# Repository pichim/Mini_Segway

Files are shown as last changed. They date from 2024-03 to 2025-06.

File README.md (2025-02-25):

# MiniSegway

The Segway is a robot that has the ability to balance itself using two motors and an IMU sensor. It is controlled with a radio transmitter in two modes, a car where it moves on the ground maintaining three points of support but also as a segway, that is, balancing on two wheels. 

<p align="center">
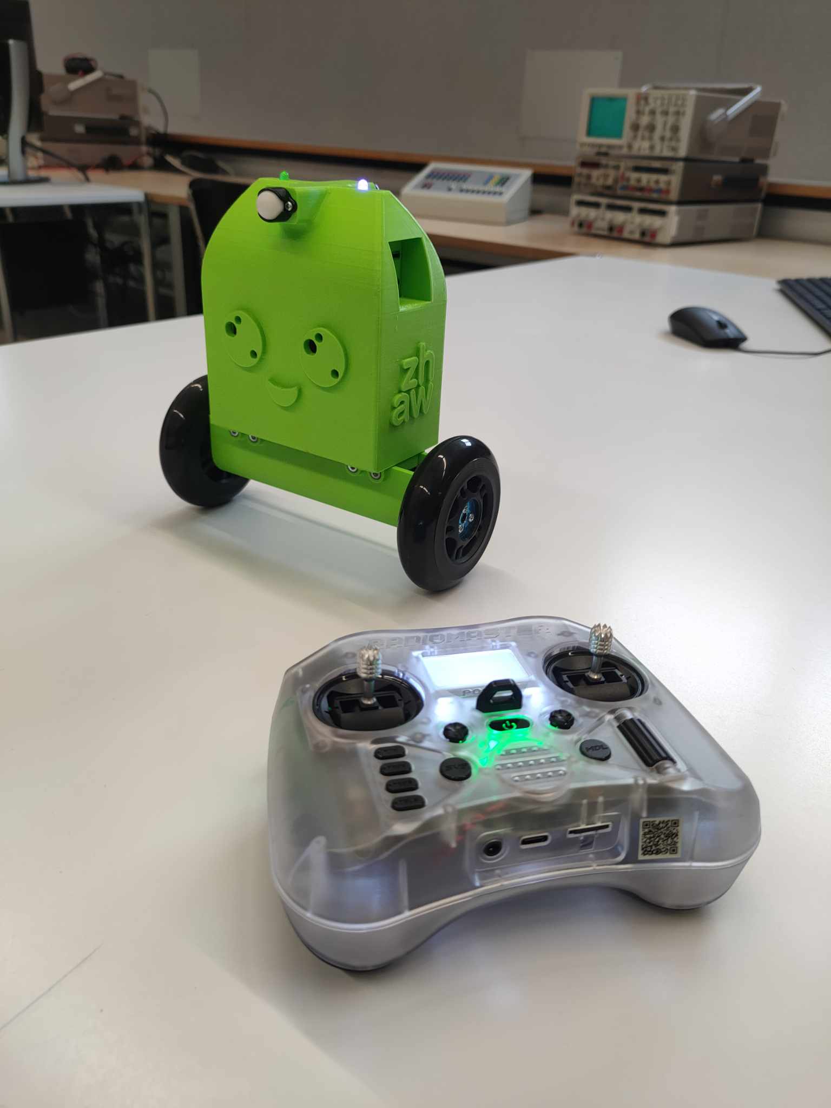
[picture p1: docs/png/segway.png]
Segway
     </br>
    <i>Segway with radio</i>
</p>

## Table of Contents

1. [Repository structure](#repository-structure)
2. [Hardware](#hardware)
3. [Prerequisites](#prerequisites)
4. [User manual](#user-manual)
5. [Software](#software)
6. [Notes](#notes)

## Repository structure

- ``/docs/cad`` - cad files with division into different extensions, including print-ready STL files and STEP files. <br>
- ``/docs/hardware`` - folder contains all hardware's datasheets and list <br>
- ``/docs/matlab`` - folder contains all development files in matlab <br>
- ``/docs/papers`` - folder contains all scientific papers regarding segway development 

## Hardware

Mechanical components (ordered) employed in design: 

- [Scooter/Skate Wheel 84×24mm][12] <br>
- [Pololu Aluminum Scooter Wheel Adapter for 4mm Shaft][13] <br>
- 2 x [Pololu Ball Caster with 1/2″ Plastic Ball][17] 

All frame parts 3D models are localized in ``docs/cad/`` folder

The list of eletric components varies from version to version, as a special PCB has been designed to eliminate some of the components and allow the battery to be charged directly on the robot. In the absence of a PCB, a list of stock components is provided.

**VERSION WITHOUT PCB**

Electrical components and sensors:

- [Nucleo-F446RE][1] <br> 
- [Pololu Dual MC33926 Motor Driver Shield for Arduino][2] <br>
- 2 x [47:1 Metal Gearmotor 25Dx67L mm MP 12V with 48 CPR Encoder][3] <br>
- [MPU6500 - 6DOF IMU][4] <br>
- [OpenLager Blackbox][5] <br>
- [RadioMaster RP2 ELRS 2.4GHz Nano Receiver][6] <br>
- [0,28" Mini Digital-Voltmeter mit LED Anzeige, 3,2-30V, 2-Wire, red][7] <br>
- [Pololu mini push-button switch][8] <br>
- 3 x [Mini Pushbutton Switch: PCB-Mount][9] <br>
- 2 x [Conrad energy NiMH battery packs 6V, 2300mAh][10] <br>
- [RadioMaster Pocket Radio Controller (ELRS)][11]<br>
- [Micro BEC 7-21V to 5V/12V-ADJ][15] <br>
- [Charger model 220v 0.5a 1a volcraft mw6168v][16] <br>
- 2 x LED diode <br>
- Jumper wires

The electronics connection is included in the file, which can be found [HERE](/docs/hardware/Segway_connection_diagram_F446RE.pdf)

**VERSION WITH PCB**

- [Nucleo-F446RE][1] <br> 
- [Pololu Dual MC33926 Motor Driver Shield for Arduino][2] <br>
- 2 x [47:1 Metal Gearmotor 25Dx67L mm MP 12V with 48 CPR Encoder][3] <br>
- [MPU6500 - 6DOF IMU][4] <br>
- [OpenLager Blackbox][5] <br>
- [RadioMaster RP2 ELRS 2.4GHz Nano Receiver][6] <br>
- [0,28" Mini Digital-Voltmeter mit LED Anzeige, 3,2-30V, 2-Wire, red][7] <br>
- [Mini Slide Switch: 3-Pin, SPDT, 0.3A][14] <br>
- 2 x [Mini Pushbutton Switch: PCB-Mount][9] <br>
- 2 x [Conrad energy NiMH battery packs 6V, 2300mAh][10] <br>
- [RadioMaster Pocket Radio Controller (ELRS)][11]<br>
- [Charger model 220v 0.5a 1a volcraft mw6168v][16] <br>
- Custom PCB
- 2 x LED diode <br>
- Jumper wires

The electronics connection is included in the file, which can be found [HERE](/docs/hardware/Segway_connection_diagram_F446RE_with_PCB.pdf) <br>
All the files related to PCB can be found in ``docs/segway_charging_board/``

Below there is components placement shown:

<p align="center">
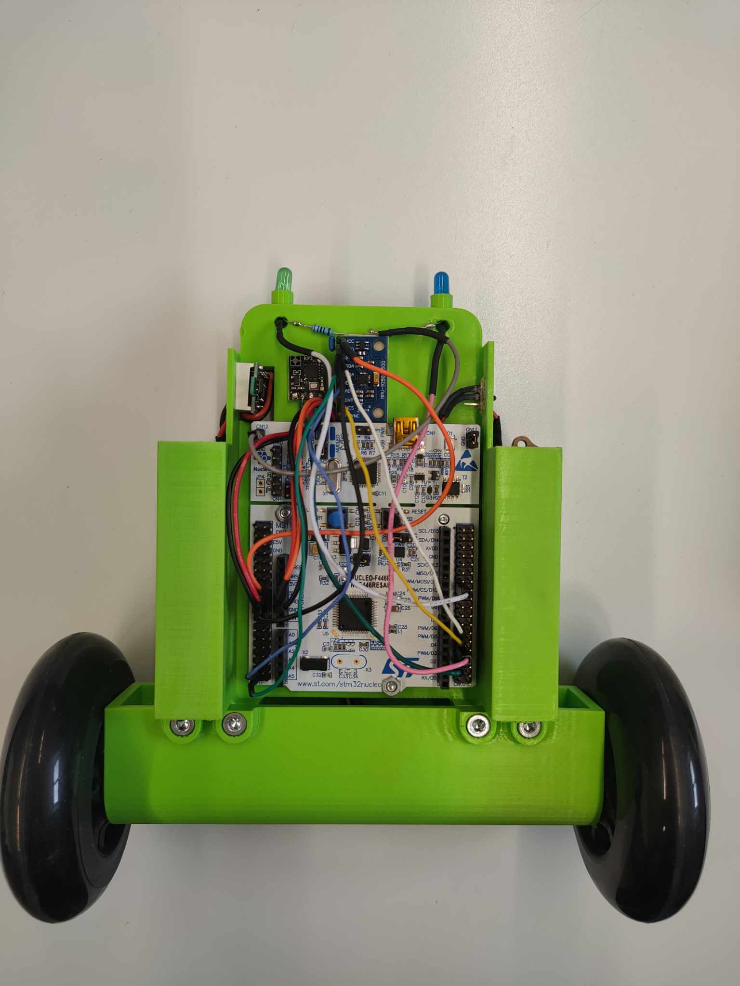
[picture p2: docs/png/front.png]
Front
     </br>
    <i>Front</i>
</p>

<p align="center">
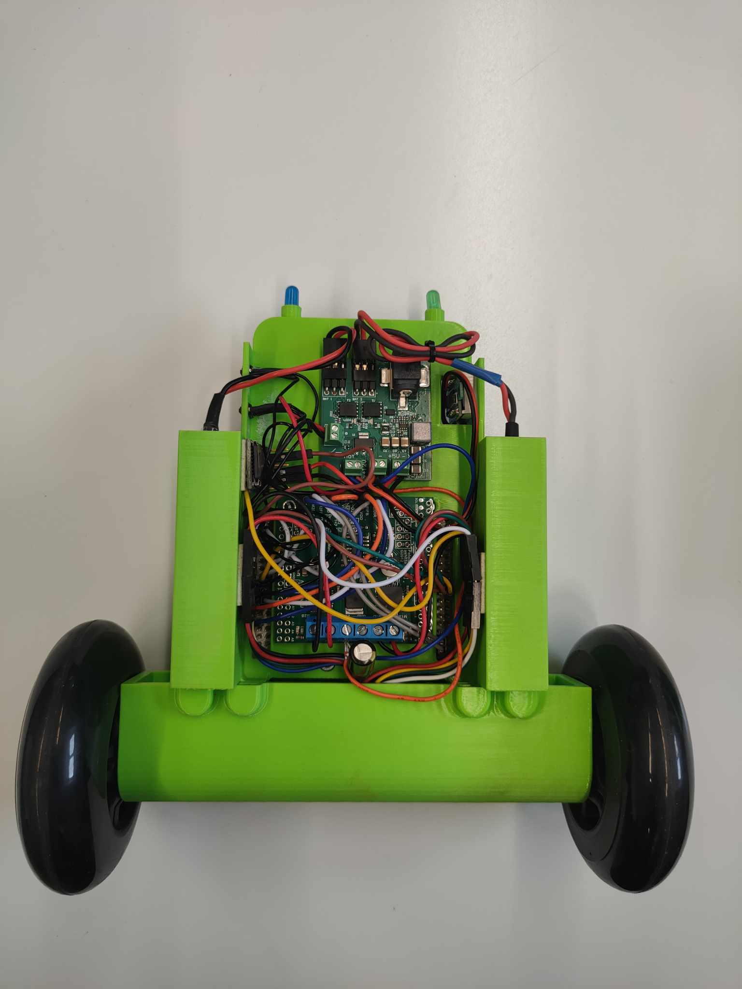
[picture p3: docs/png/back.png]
Back
     </br>
    <i>Back</i>
</p>

## Prerequisites

- Mbed Studio
- Libraries:
    - mbed-os 6.17.0
    - eigen

All the libraries you need are included in the repository. Software is mostly based on files located in /src folder and main logic is included in MiniSegway class that is running in own thread.

## User manual

### Running the project for the first time

In order to run the project you need to import program to Mbed Studio and follow next steps:
- as the board is using external power source, board has jumper JP5 switched to E5V postion which requires to first supply board with external power and then plug it in to the computer
- now program can be compiled and flashed to the board

### Using robot

In order to use the robot you must follow the steps below:
- Start the radio controller that is paired with the receiver on the robot
- Turn on the power supply on the robot (in this situation both LED, green and blue will start blinking)
- Arm the radio controler (SD button) (in such case the green LED will start to shine continuously)
- Then the USER button on the robot can be pressed, which will lead the robot to CAR mode (blue LED will start to shine continuously) [picture below]
- To use the robot as segway, raise it to a standing position and wait until the robot visibly starts to balance.
- By default, the robot is in normal mode, however, when you press the button on the radio transmitter (SA button), the robot will go into fast mode, and its speed will be increased (**NOTES: In normal mode, the robot is practically unturnable when controlling the radio transmitter (as long as there is no collision, of course), however, in fast mode there is the possibility of such control, which will lead to loss of balance.**)

<p align="center">
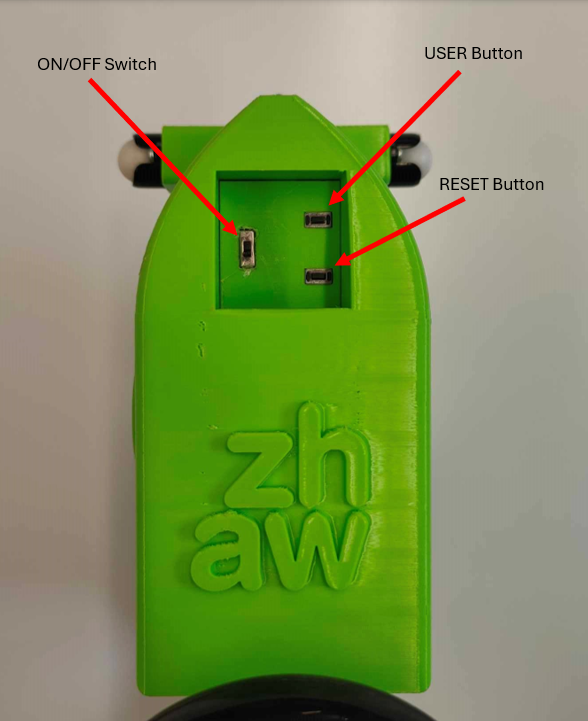
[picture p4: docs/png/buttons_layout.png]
Buttons layout
     </br>
    <i>Button layout</i>
</p>

## Software

### main.cpp

The *main.cpp* file contains only the declaration of the rc class, which handles communication with the radio transmitter, and the minisegway, which contains all the program logic. Inside the file you can also find the declaration of an additional button that serves as the RESET of the system.

### config.h

The *config.h* file is very important due to the fact that it contains all the declarations of the robot's parameters and the names of the pins used to connect the hardware. Importantly, it also contains options for changing the robot's configuration, i.e. enabling or disabling certain options such as data transfer (over the link or to an SD card), measurements with additional current sensors, or a function for testing the frequency response with a chirp signal. 
This file should be used for all configurations related to changing the parameters of the robot, changing the parameters of the filters and any changes to the pin maps.

### minisegway.cpp

Minisegway is a class that operates in its own thread with a frequency of 1kHz. In it there are declarations of all objects communicating with the hardware that is mounted on the robot. Inside the class you can find the state machine, because as mentioned the robot moves in two modes, as a car or as a segway. The file also includes additional functions, used during debugging and testing of the hardware operation.

#### IMU

The IMU class is initialized when the MiniSegway class is initialized, the first step that is performed inside the IMU is to configure and check the connection which is signaled by returning the device ID to the output window.The device is then calibrated, with the first thousand measurement points omitted due to the fact that they deviate significantly from the norm and there are fluctuations associated with the initialization process.

In addition, position mapping is performed due to the target position of the robot and the positioning of the IMU on the robot:

1. **Roll Control Advantage**: The alignment allows the use of roll for controlling the Segway. Roll control is preferred because yaw control can encounter singularities (undefined or unstable behavior) at angles of ±90 degrees when the Segway is upright.

2. **IMU Orientation**:
   - **X-Axis**: The IMU's x-axis is oriented to point to the left side of the Segway.
   - **Y-Axis**: The IMU's y-axis is oriented to point towards the back of the Segway.
   - **Z-Axis**: The IMU's z-axis is oriented to point upwards.

In case of completion of the calibration process, a flag is sent confirming the completion of the process so that further execution of the program in the minisegway class can be executed.

#### State space controller

This state-space controller is designed to keep a Segway in a vertical position by controlling the robot's velocity input based on various sensor readings and setpoints. The control strategy involves multiple proportional (P) and derivative (D) components applied to different states of the system:

1. **Position Control ( u_p_{pos} )**:
   - **Proportional Control on Position**: 
     - `robotVelSetpointIntegrator.apply(robot_vel_setpoint(0))` is the integrated velocity setpoint, which essentially gives the desired position setpoint.
     - `robot_pos(0)` is the current position of the Segway.
     - `MINI_SEGWAY_CP_POS_KP` is the proportional gain for position control.
     - The difference between the desired position setpoint and the current position is multiplied by the proportional gain to produce the position control effort `u_p_pos`.

2. **Velocity Control (u_p_{vel}  and u_d_{vel})**:
   - **Proportional Control on Velocity**:
     - `robot_vel(0)` is the current velocity of the Segway.
     - `MINI_SEGWAY_CPD_VEL_KP` is the proportional gain for velocity control.
     - The current velocity is multiplied by the proportional gain to produce the velocity control effort `u_p_vel`.
   - **Derivative Control on Velocity**:
     - `acc_x_filtered` is the filtered acceleration along the x-axis.
     - `MINI_SEGWAY_CPD_VEL_KD` is the derivative gain for velocity control.
     - The filtered acceleration is multiplied by the derivative gain to produce the velocity derivative control effort `u_d_vel`.

3. **Angle Control (u_p_{ang} and u_d_{ang})**:
   - **Proportional Control on Angle**:
     - `imu_data.rpy(0)` is the roll (angle) of the Segway as measured by the IMU (Inertial Measurement Unit).
     - `MINI_SEGWAY_CPD_ANG_KP` is the proportional gain for angle control.
     - The roll angle is multiplied by the proportional gain to produce the angle control effort `u_p_ang`.
   - **Derivative Control on Angle**:
     - `gyro_theta_filtered` is the filtered angular velocity (rate of change of angle).
     - `MINI_SEGWAY_CPD_ANG_KD` is the derivative gain for angle control.
     - The filtered angular velocity is multiplied by the derivative gain to produce the angle derivative control effort `u_d_ang`.

4. **Combining Control Efforts**:
   - The control efforts from the position, velocity, and angle controllers are combined to produce the total control input.
   - The equation `robot_vel_input(0) = -1.0f * (u_p_pos - (u_p_vel + u_d_vel + u_p_ang + u_d_ang))` combines these efforts. The negative sign indicates that the control input is used to counteract deviations from the desired state, aiming to keep the Segway upright.

## Notes:

In the event that a version of Segway will be assembled that does not have a custom PCB, the arrangement of additional hardware will cause the IMU to be on the other side of the robot. In this case, changes must be made to the software in order for the robot to function properly. In the 45th line of **IMU.cpp** file located in ``src`` folder, is following code, that is working only with the version with custom PCB:

```
    // segway imu alignment:
    // the alignment was chosen so that roll can be used for controlling
    // the segway since yaw has a singularity at +/-90 deg
    //   when standing upright, the IMU is mounted on the robot with:
    //   - the x-axis pointing to the right
    //   - the y-axis pointing forwards
    //   - the z-axis pointing upwards
    Eigen::Vector3f gyro(m_ImuMPU6500.gyroX, -m_ImuMPU6500.gyroZ, m_ImuMPU6500.gyroY);
    Eigen::Vector3f acc(m_ImuMPU6500.accX, -m_ImuMPU6500.accZ, m_ImuMPU6500.accY);
```

To match the code to a different orientation of the IMU, i.e., located on the other side of the robot, you need to change the characters of the data coming from each axis as shown in the illustration below.

```
    // segway imu alignment:
    // the alignment was chosen so that roll can be used for controlling
    // the segway since yaw has a singularity at +/-90 deg
    //   when standing upright, the IMU is mounted on the robot with:
    //   - the x-axis pointing to the left
    //   - the y-axis pointing backwards
    //   - the z-axis pointing upwards
    Eigen::Vector3f gyro(-m_ImuMPU6500.gyroX, m_ImuMPU6500.gyroZ, m_ImuMPU6500.gyroY);
    Eigen::Vector3f acc(-m_ImuMPU6500.accX, m_ImuMPU6500.accZ, m_ImuMPU6500.accY);
```

[1]: https://os.mbed.com/platforms/ST-Nucleo-F446RE/
[2]: https://www.play-zone.ch/en/pololu-dual-mc33926-motor-driver-shield-for-arduino.html
[3]: https://www.pololu.com/product/4865
[4]: https://www.smart-prototyping.com/MPU6500-6DOF-Sensor-Breakout-Board
[5]: https://www.racedayquads.com/products/airbot-openlager-blackbox
[6]: https://fpvracing.ch/de/funksystem/3575-radiomaster-rp2-elrs-24ghz-nano-receiver.html?
[7]: https://www.berrybase.ch/0-28-mini-digital-voltmeter-mit-led-anzeige-3-2-30v-2-wire-rot
[8]: https://www.pololu.com/product/2808
[9]: https://www.pololu.com/product/1400
[10]: https://www.conrad.ch/de/p/reely-modellbau-akkupack-nimh-6-v-2300-mah-zellen-zahl-5-mignon-aa-side-by-side-jr-buchse-2613252.html
[11]: https://fpvracing.ch/de/funksystem/3785-radiomaster-pocket-radio-controller-elrs.html?
[12]: https://www.pololu.com/product/3275
[14]: https://www.pololu.com/product/1408
[13]: https://www.pololu.com/product/2672
[15]: https://www.mateksys.com/?portfolio=mbec2a#tab-id-2
[16]: https://eclats-antivols.fr/en/ean/24811-chargeur-de-modelisme-220-v-1-a-voltcraft-mw6168v-nicd-nimh-4016138642414.html
[17]: https://www.pololu.com/product/952

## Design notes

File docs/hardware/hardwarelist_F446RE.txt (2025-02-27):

Nucleo-F446RE
- https://os.mbed.com/platforms/ST-Nucleo-F446RE/

Pololu Dual MC33926 Motor Driver Shield for Arduino
- https://www.play-zone.ch/en/pololu-dual-mc33926-motor-driver-shield-for-arduino.html

2 x 47:1 Metal Gearmotor 25Dx67L mm MP 12V with 48 CPR Encoder
- https://www.pololu.com/product/4865

MPU6500 - 6DOF IMU
- https://invensense.tdk.com/products/motion-tracking/6-axis/mpu-6500/
- https://www.smart-prototyping.com/MPU6500-6DOF-Sensor-Breakout-Board
- MPU-6500-Register-Map2.pdf
- PS-MPU-6500A-01-v1.3.pdf
- 1.71-3.45V

OpenLager Blackbox
- https://www.racedayquads.com/products/airbot-openlager-blackbox
- 3.3-5.5V

RP1 V2 ExpressLRS 2.4ghz Nano Receiver
- https://www.radiomasterrc.com/products/rp1-expresslrs-2-4ghz-nano-receiver
- 5V

0,28" Mini Digital-Voltmeter mit LED Anzeige, 3,2-30V, 2-Wire, red
- https://www.berrybase.ch/0-28-mini-digital-voltmeter-mit-led-anzeige-3-2-30v-2-wire-rot

Pololu mini push-button switch with reverse polarity protection
- https://www.pololu.com/product/2808

3 x Mini Pushbutton Switch: PCB-Mount, 2-Pin, SPST, 50mA (5-Pack)
- https://www.pololu.com/product/1400

2 x LED diode

2 x Conrad energy NiMH battery packs 6V, 2300mAh
- https://www.conrad.ch/de/p/reely-modellbau-akkupack-nimh-6-v-2300-mah-zellen-zahl-5-mignon-aa-side-by-side-jr-buchse-2613252.html

Jumper wires	

GS-9018 Servo
- http://www.goteckrc.com/ProductShow.asp?ID=10

Micro BEC 6-30V to 5V/9V-ADJ
- https://www.mateksys.com/?portfolio=mbec6s

CADDXFPV Nebula Pro Vista Kit
- https://caddxfpv.com/products/nebula-pro-vista-kit-720p-120fps-low-latency-hd-digital-fpv-system

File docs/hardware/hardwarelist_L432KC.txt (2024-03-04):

NUCLEO-L432KC
- https://os.mbed.com/platforms/ST-Nucleo-L432KC/
- https://community.st.com/t5/stm32-mcus-boards-and-hardware/how-to-power-nucleo-f303k8-or-nucleo-l432kc-with-an-external/td-p/111820

MATEKSYS Micro BEC 6-30V to 5V/9V-ADJ
- https://www.mateksys.com/?portfolio=mbec6s
- Input 6-30V
- Output 5V, 1.5A cont., 2.5A max

2x SparkFun 9DoF Sensor Stick
- https://www.sparkfun.com/products/retired/13944
- lsm9ds1.pdf
- 1.9-3.6V

OpenLager
- https://www.racedayquads.com/products/airbot-openlager-blackbox
- 3.3-5.5V

TBS CROSSFIRE Nano RX
- https://www.team-blacksheep.com/products/prod:crossfire_nano_rx
- tbs-crossfire-nano-quickstart.pdf
- 5V

Pololu A4990 Dual Motor Driver Carrier
- https://www.pololu.com/product/2137
- A4990-Datasheet.pdf
- a4990-dual-motor-driver-carrier-schematic-diagram.pdf
- https://www.pololu.com/product/2512
- https://github.com/pololu/a4990-motor-shield
- Enable 2.0-5.0V
- Motor power 6-32V

2x Pololu 298:1 Micro Metal Gearmotor HPCB 12V with Extended Motor Shaft
- https://www.pololu.com/product/3056

2x Pololu 150:1 Micro Metal Gearmotor HPCB 12V with Extended Motor Shaft
- https://www.pololu.com/product/3053

Pololu Magnetic Encoder Pair Kit for Micro Metal Gearmotors, 12 CPR, 2.7-18V
- https://www.pololu.com/product/3081
- 2.7-18.0V

Optical Encoder Pair Kit for Micro Metal Gearmotors, 5V
- https://www.pololu.com/product/2590

Pale Blue PB-9V
- https://www.digitec.ch/en/s1/product/pale-blue-pb-9v-2-pcs-9v-500-mah-batteries-17438462
- https://paleblueearth.com/products/pale-blue-lithium-ion-rechargeable-9v-batteries

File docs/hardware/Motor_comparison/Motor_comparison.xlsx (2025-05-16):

Motor
Brand, series | Pololu 47:1 Metal Gearmotor 25Dx67L mm MP 12V with 48 CPR Encoder |  | A-max 22 Ø22 mm, Graphite Brushes, 6 Watt, with terminals Part number 110161 / 353025 | A-max 22 Ø22 mm, Graphite Brushes, 6 Watt, with terminals Part number 110160 / 231171 | DC-max 22 S Ø22 mm, graphite brushes, ball bearings
Comparing position
Nominal voltage (V) | 12 |  | 12 | 12 | 12
No load speed (RPM) | 7964.5 |  | 9170 | 10200 | 7140 | 1.280683031
Nominal speed (RPM) | - |  | 6000 | 7060 | 5260
No load current (mA) | - |  | 40.5 | 45.8 | 28.3
Nominal current (A) | - |  | 0.613 | 0.681 | 0.819
Stall current (A) | - |  | 1.72 | 2.17 | 3.14
Nominal torque (mNm) | 6.59 |  | 6.95 | 6.96 | 12.5
Stall torque (mNm) | 22.34 |  | 20.9 | 23.7 | 49.4
Shaft diameter (mm) | - |  | 2 | 2 | 2
Shaft length (mm) | - |  | 6.5 | 6.5 | 10
Torque constant (mNm/A) | 10.72 |  | 12.1 | 10.9 | 15.8 | 1.318350179
Speed constant (RPM/V) | 663.71 |  | 790 | 875 | 606
Weight (g) | - |  | 54 | 54 | 54
Size (mm) | 25D x 30.8L |  | 22D x 31.9L | 22D x 31.9L | 22D x 32L
Max power (W) (mechanical) | - |  | 6 | 6 | 8
Price (for 10 units) | - |  | 68.52 | 59.79 | 72.84
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

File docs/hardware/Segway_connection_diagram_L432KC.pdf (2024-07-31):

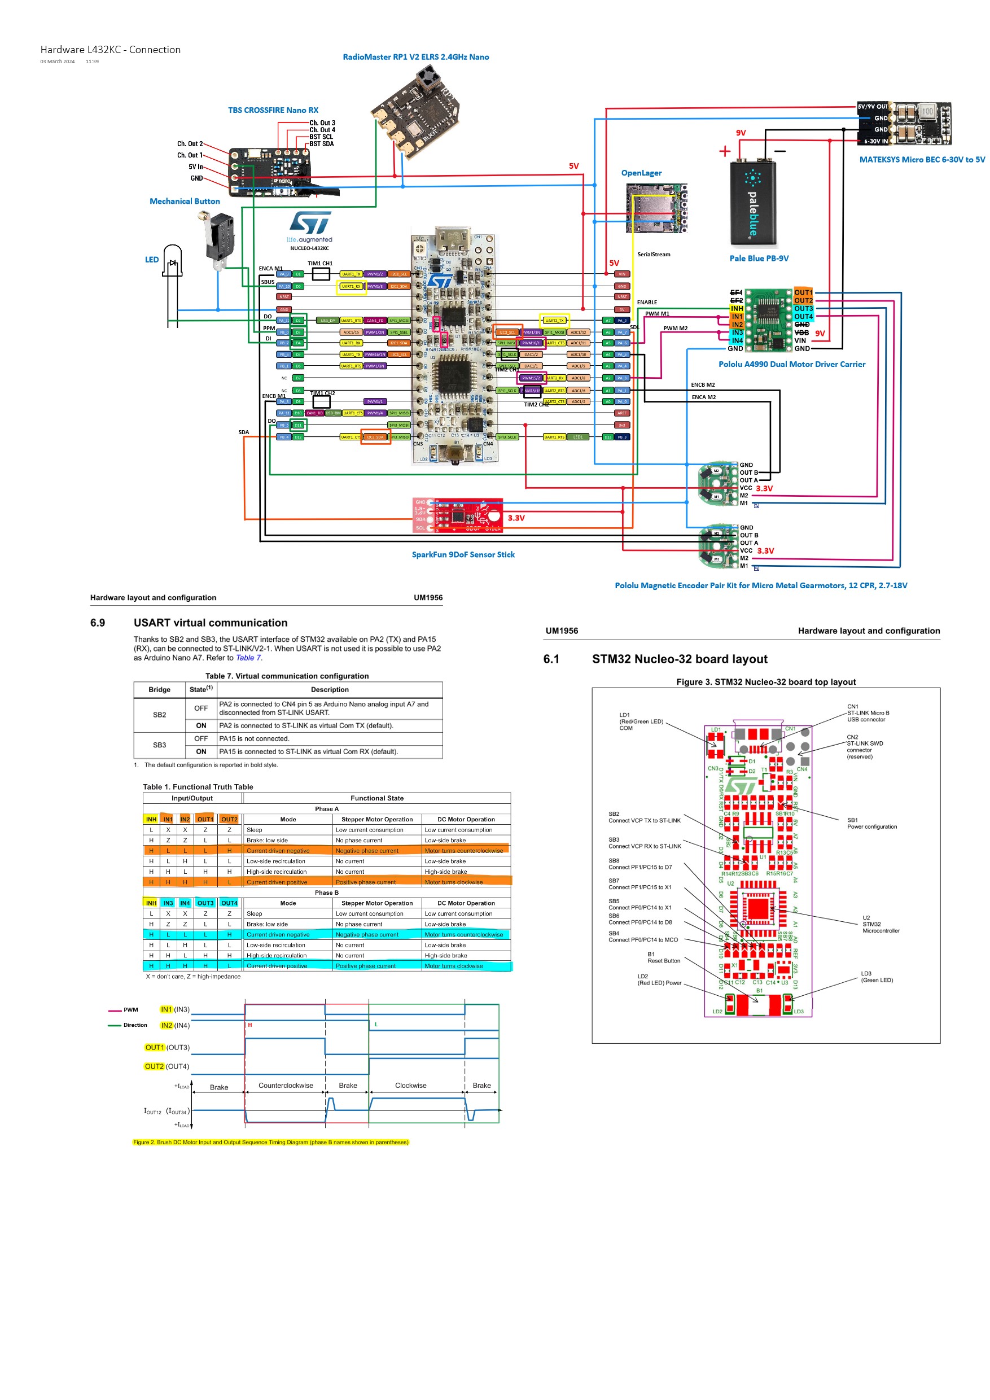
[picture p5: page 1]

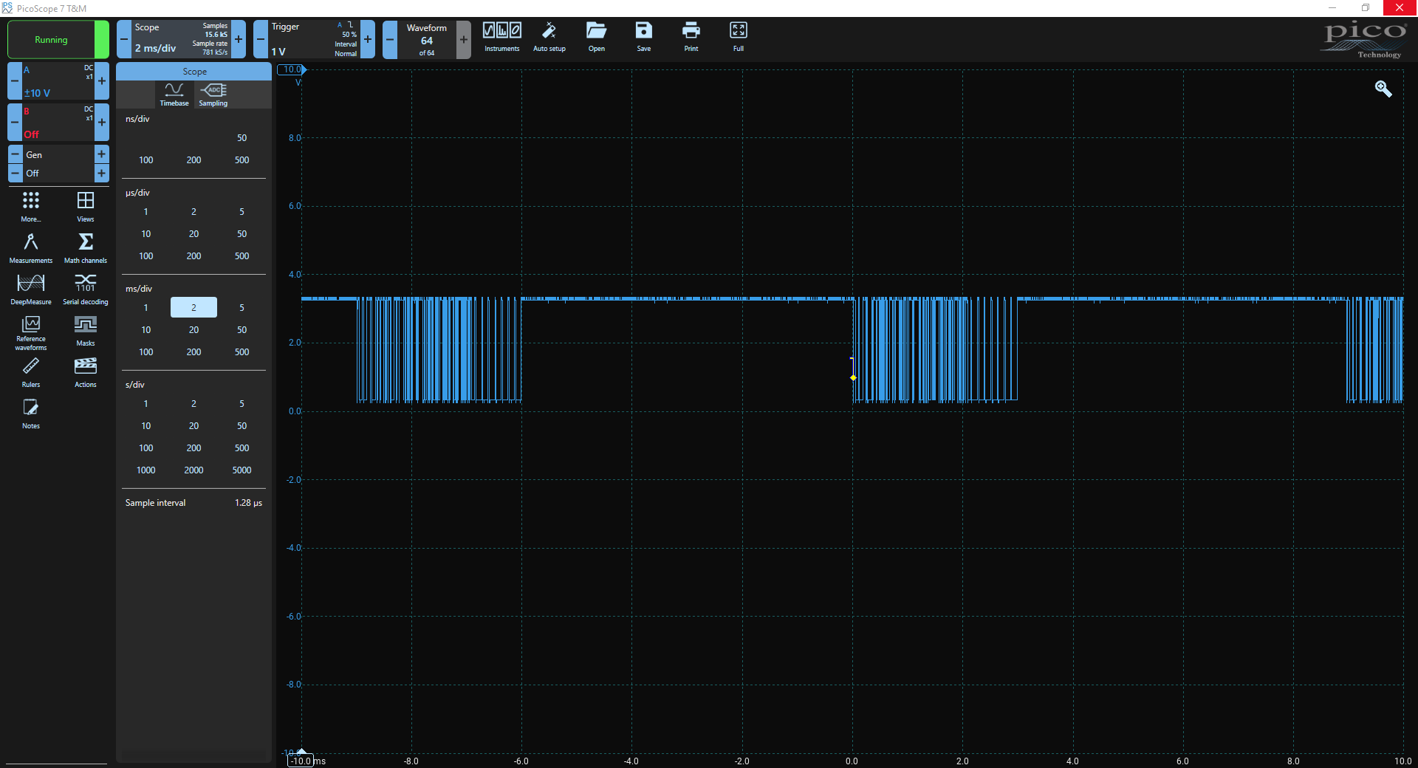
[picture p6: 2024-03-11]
docs/hardware/elrs_sbus/20240229_picoscope_snapshot.PNG

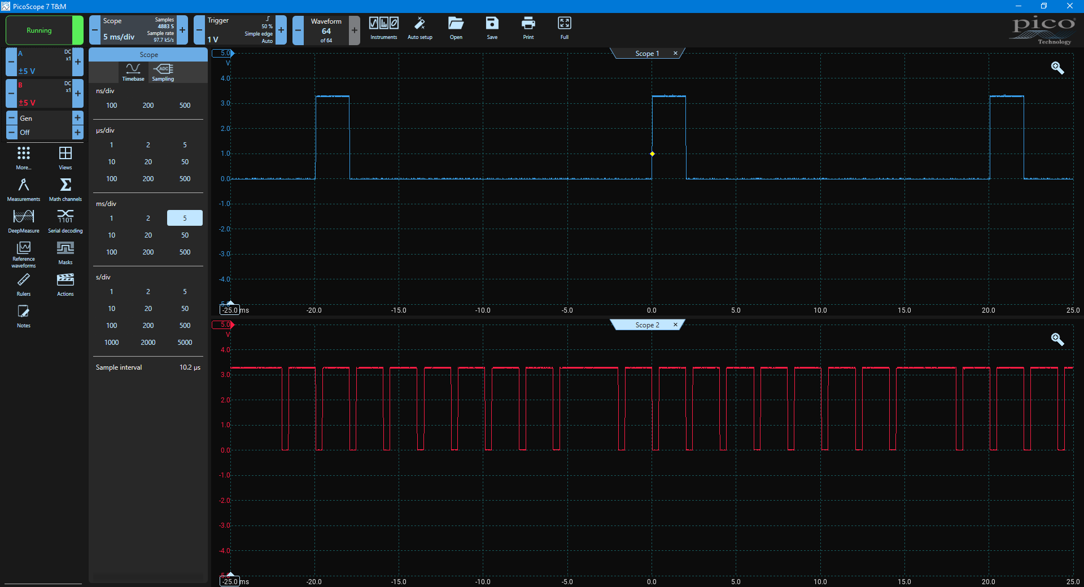
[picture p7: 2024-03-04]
docs/hardware/elrs_sbus/20240229_picoscope_snapshot_8_channels_all_max.PNG

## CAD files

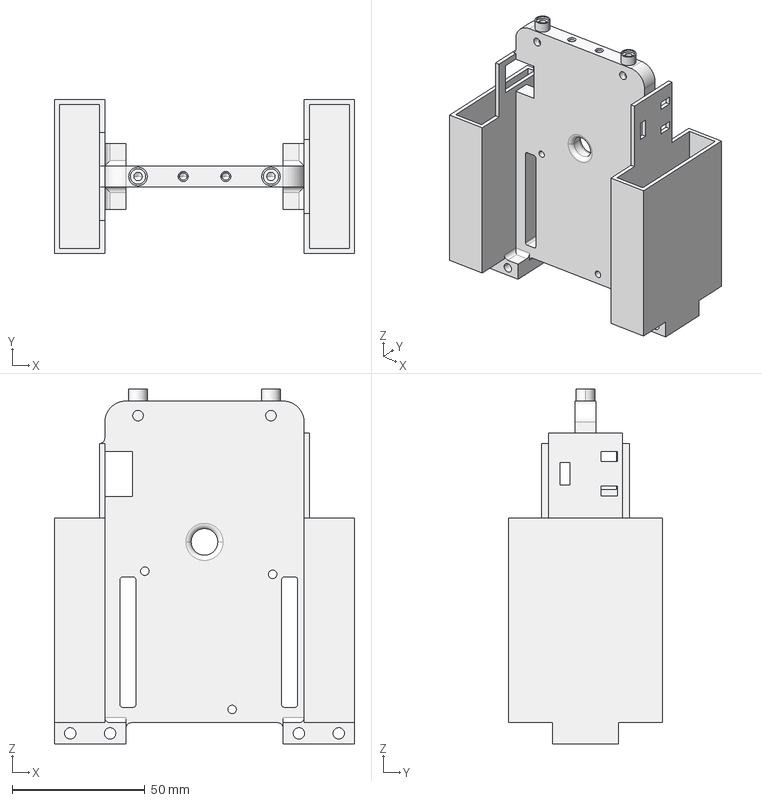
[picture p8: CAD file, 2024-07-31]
docs/cad/NDT_FRAME_MAIN_V1.stp
113.0 x 58.0 x 133.5 mm

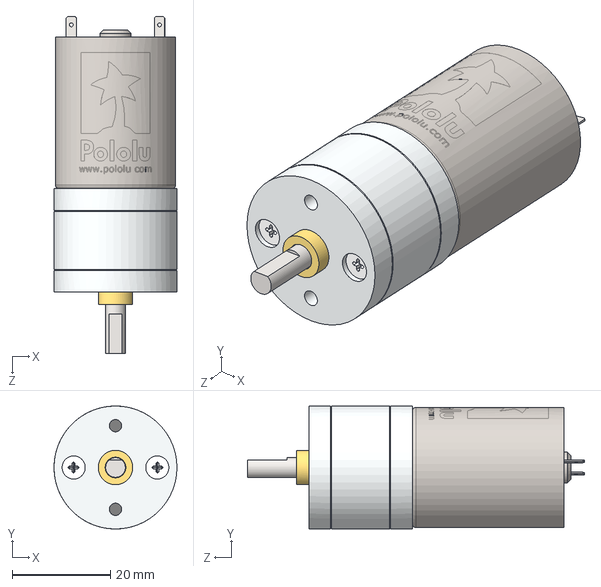
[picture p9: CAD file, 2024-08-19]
docs/cad/25d-metal-gearmotor-34-47.step
25.0 x 25.0 x 68.5 mm

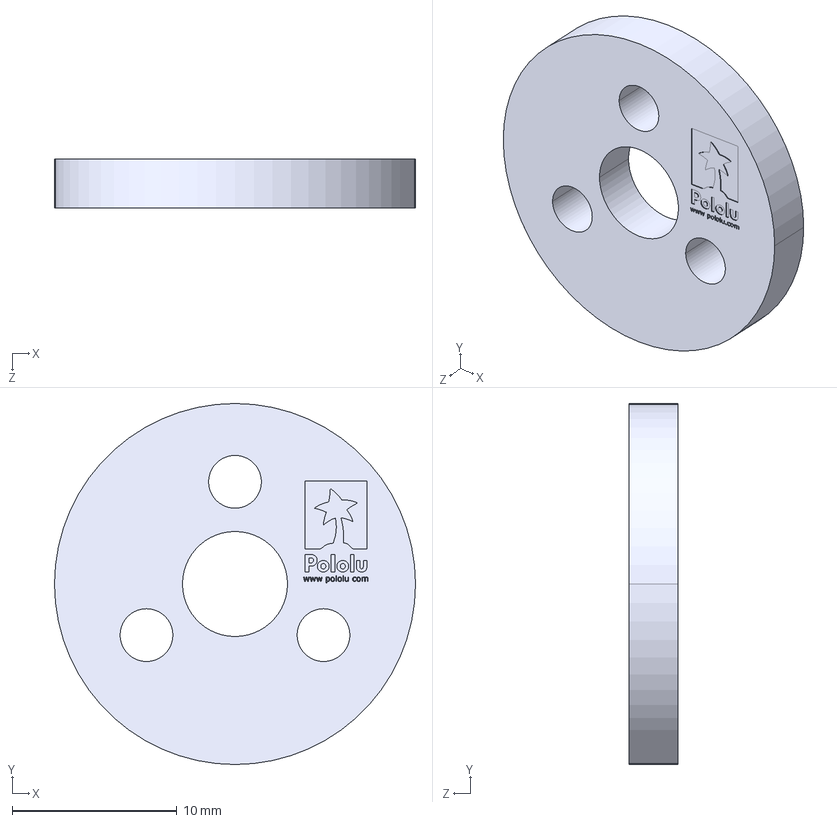
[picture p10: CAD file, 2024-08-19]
docs/cad/pololu-aluminum-scooter-wheel-adapter-dwa01b.step
21.9 x 21.9 x 3.00 mm

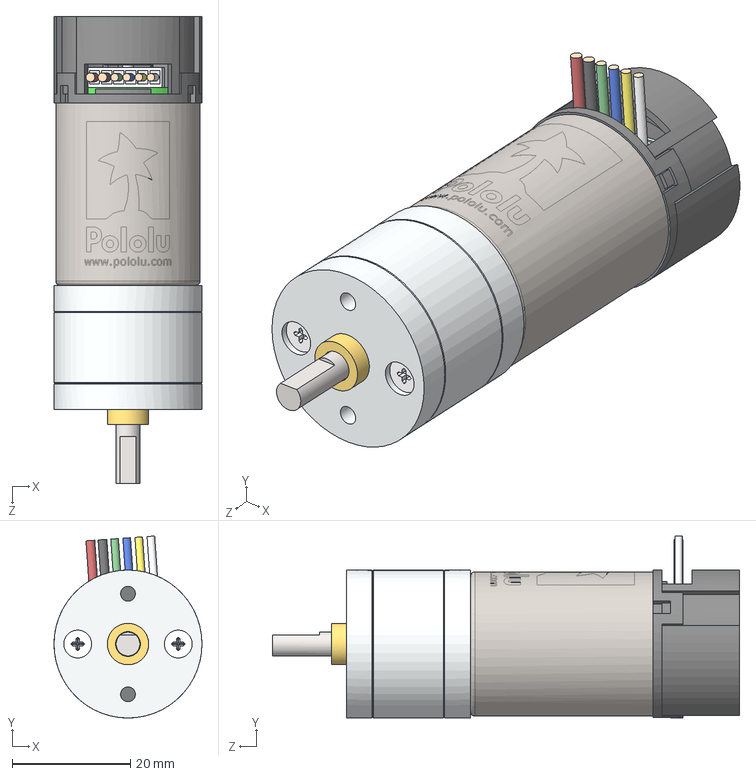
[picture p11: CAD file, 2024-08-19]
docs/cad/25d-metal-gearmotor-34-47-encoder.step
25.0 x 30.8 x 79.0 mm

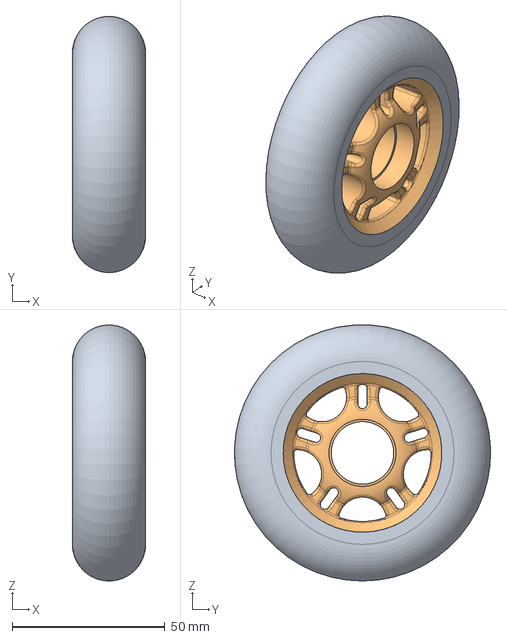
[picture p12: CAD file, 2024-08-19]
docs/cad/Skate Wheel 84×24mm - Black.step
24.0 x 84.0 x 83.9 mm

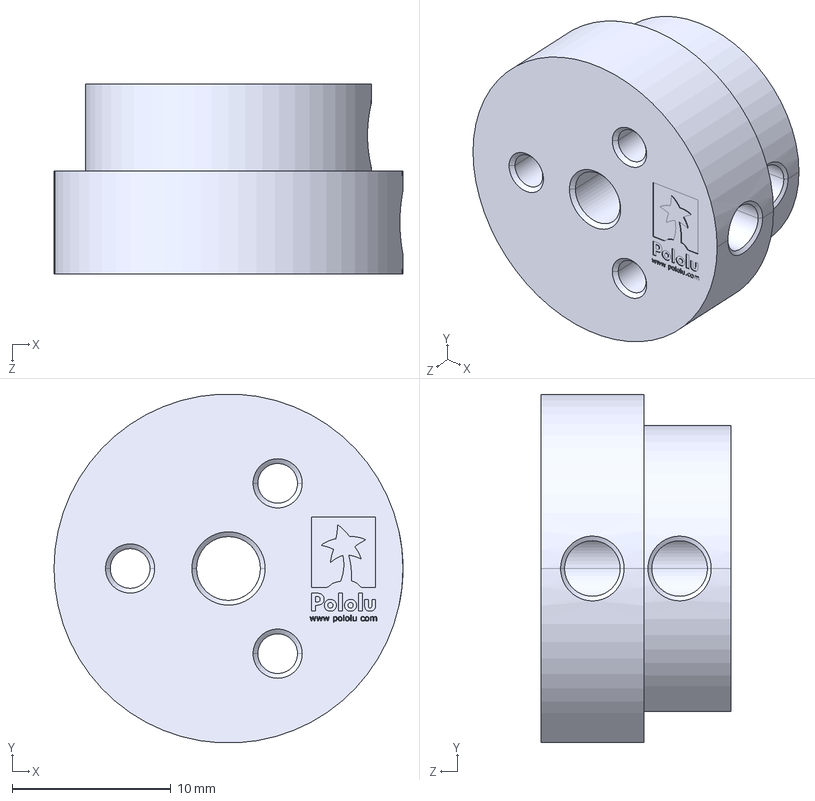
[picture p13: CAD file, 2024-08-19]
docs/cad/pololu-aluminum-scooter-wheel-adapter-4mm.step
22.0 x 22.0 x 12.0 mm

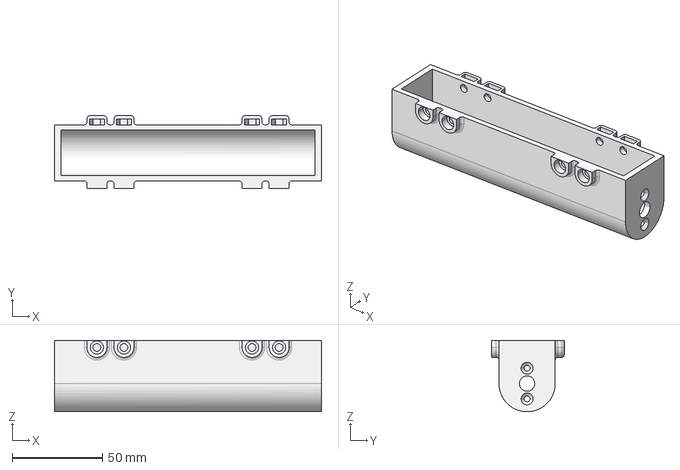
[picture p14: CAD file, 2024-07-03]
docs/cad/NDT_FRAME_WHEEL_BASE.stp
148.0 x 40.2 x 39.6 mm

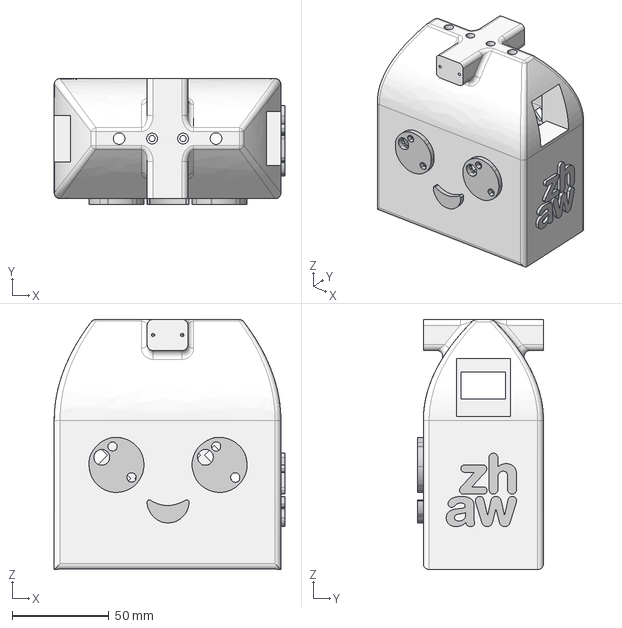
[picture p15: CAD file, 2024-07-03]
docs/cad/NDT_ROBOT_COVER.stp
119.0 x 65.0 x 129.0 mm

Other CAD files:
docs/cad/NDT_FRAME_MAIN_V1.stl
docs/cad/NDT_FRAME_WHEEL_BASE.stl
docs/cad/NDT_ROBOT_COVER.stl

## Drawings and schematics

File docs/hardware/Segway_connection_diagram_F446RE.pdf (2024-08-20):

### Hardware F446RE - Connection

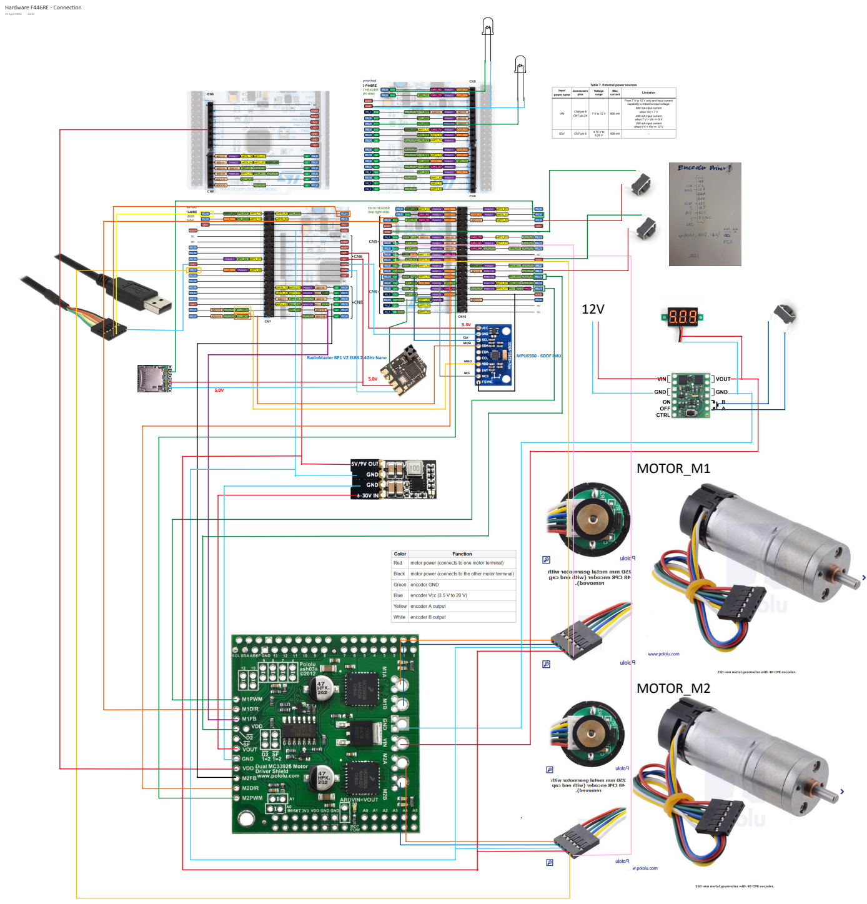
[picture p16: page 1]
RadioMaster RP1 V2 ELRS 2.4GHz Nano; MPU6500 - 6DOF IMU; CLK MOSI; MISO; NCS; MOTOR_M1; MOTOR_M2; 15 April 2024

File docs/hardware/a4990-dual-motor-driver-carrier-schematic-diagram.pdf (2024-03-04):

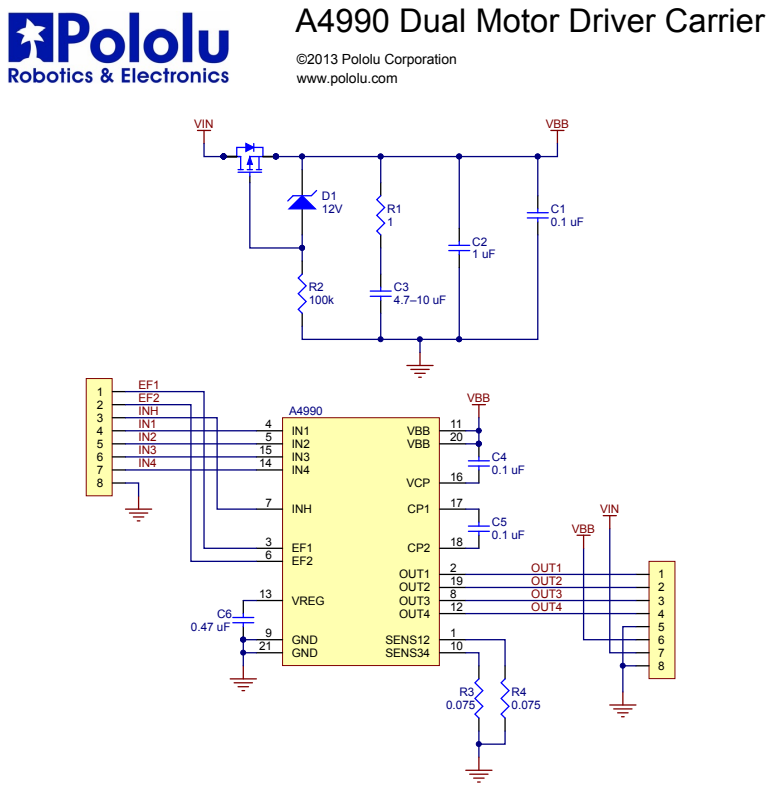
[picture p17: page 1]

A4990 Dual Motor Driver Carrier

EF2
INH

IN2 | IN2 5
IN3 | IN4 14 IN3 15
IN4

INH 7

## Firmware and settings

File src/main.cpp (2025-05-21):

#include "mbed.h"

#include "DebounceIn.h"
#include "MiniSegway.h"
#include "RC.h"

// Notes:
// - Acc signal has a clear offset, this was different via spi with the imu breakout board

// TODOs:
// - check motor constant kn                                     ok, measured
// - check motor cpr at gear end                                 ok
// - check motor pwm                                             ok, increased from 5 kHz to 20 kHz (now at max)
// - remove pes_board_pinmap.h (maybe) for what ever reason      can't, otherwise Camille is mad
// - check imu filter configuration                              ok, according to the code, did not check spectras
// - check imu alignment                                         ok, adjusted based on measurement
// - check imu units                                             ok, adjusted based on measurement
// - maybe sampling time needs to be adjusted to 2 ms (500 Hz)   ok, we leave it at 1 kHz
// - check sd card logging                                       ok, you need to use the blue button to end the logging to get valid data
// - check the sign of all data when logging while driving       ok
// - adjust controller parameters
// - add gimbal, set paramters in config.h and remove TODOs
// - check all TODOs
// - update README.md

RC rc(MINI_SEGWAY_RC_UART_RX); // rc needs to be declared here and passed to miniSegway
MiniSegway miniSegway(rc);

int main()
{
    while (true) {
        thread_sleep_for(1000);
    }
}

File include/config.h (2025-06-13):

#pragma once

#ifndef M_PIf
    #define M_PIf 3.14159265358979323846f /* pi */
#endif

#include "pes_board_pinmap.h"

// currently used hardware
// - 1 x openlager (UART)                                              (ok)
// - 1 x serial via programming port to laptop / pc (UART)             (ok)
// - 1 x serial via usb 2.0-cable TTL serial 6 pin to computer (UART)  (ok)
// - 1 x remote control receiver, radiomaster elrs (UART)              (ok)
// - 2 x additional buttons (enable, reset) (GPIOs)                    (ok)
// - 2 x additional leds (DOUT)                                        (ok)
// - 2 x encoder                                                       (ok)
// - 1 X enable motor driver (GPIO)                                    (ok)
// - 2 x motor pwm (PWM)                                               (ok)
// - 2 x motor direction (DOUT)                                        (ok)
// - 1 x imu (SPI)                                                     (ok)
// - 2 x motor current sensor (AIN)                                    (ok)
// - 1 x gimbal servo (DOUT)                                           (ok)

// task period, MPU6500 runs at 1kHz, so we want to run the control loop at 1kHz
#define MINI_SEGWAY_PERIOD_US 1000
#define MINI_SEGWAY_TS (static_cast<float>(MINI_SEGWAY_PERIOD_US) * 1.0e-6f) // sampling time
#define MINI_SEGWAY_ABS_ANGLE_START_BALANCE_RAD (20.0f * M_PIf / 180.0f)
#define MINI_SEGWAY_ABS_ANGLE_STOP_BALANCE_RAD (50.0f * M_PIf / 180.0f)
#define MINI_SEGWAY_MIXER_GAIN 0.7f // e.g. 0.7f means 70% of the control signal is used forward speed and 30% for turning
#define MINI_SEGWAY_SCALE_SPEED_MAX_FAST 0.8f * 1.0f
#define MINI_SEGWAY_SCALE_SPEED_MAX_SLOW 0.8f * 0.6f
#define MINI_SEGWAY_R_WHEEL 0.039f // wheel radius in meters
#define MINI_SEGWAY_B_WHEEL 0.125f // wheelbase, distance from wheel to wheel in meters

// state space controller gains
#define MINI_SEGWAY_FORWARD_CPD_ANG_KP 1.2f * 2.64f
#define MINI_SEGWAY_FORWARD_CPD_ANG_KD 1.5f * 0.05f
#define MINI_SEGWAY_FORWARD_CPD_ANG_D_FILTER_FREQUENCY_HZ 3.0f
#define MINI_SEGWAY_FORWARD_CPD_VEL_KP 1.1f * 2.2f
#define MINI_SEGWAY_FORWARD_CPD_VEL_KD 2.0f * 0.05f
#define MINI_SEGWAY_FORWARD_CPD_VEL_D_FILTER_FREQUENCY_HZ 1.0f
#define MINI_SEGWAY_FORWARD_CP_POS_KP 0.8f * 2.86f
#define MINI_SEGWAY_TURN_CP_POS_KP 10.0f

// streaming device, openlager or laptop / pc
#define DO_USE_OPENLAGER_FOR_DATA_STREAM true
// serial data stream, tested up to 20 floats at 2 kHz
#if DO_USE_OPENLAGER_FOR_DATA_STREAM
    // openlager, needs to be stopped via blue botton, otherwise no valid data
    #define MINI_SEGWAY_UART_TX PB_UART3_TX // UART6_TX
    #define MINI_SEGWAY_UART_RX NC
#else
    // // serial via usb to matlab
    // #define MINI_SEGWAY_UART_TX USBTX // PA_2, UART2_TX
    // #define MINI_SEGWAY_UART_RX USBRX // PA_3, UART2_RX
    // usb 2.0-cable TTL serial 6 pin to computer
    #define MINI_SEGWAY_UART_TX PB_UART3_TX // UART3_TX (PC_10)
    #define MINI_SEGWAY_UART_RX PB_UART3_RX // UART3_RX (PC_11)
#endif
// openlager runs at 2000000 baudrate
#define MINI_SEGWAY_BAUDRATE 2000000
#define MINI_SEGWAY_NUM_OF_FLOATS 31 // tested up to 20 floats at 2 kHz, so 31 floats at 1 kHz should work

// remote control receiver, radiomaster elrs rx, running at 111 Hz := ~9000 mus
#define MINI_SEGWAY_RC_UART_TX NC
#define MINI_SEGWAY_RC_UART_RX PB_UART5_RX // UART2_RX
#define MINI_SEGWAY_RC_NUM_OF_ALLOWED_INVALID_DATA_PKG (10 * (9000 / MINI_SEGWAY_PERIOD_US + 1))
#define MINI_SEGWAY_RC_NUM_OF_NECESSARY_VALID_DATA_PKG MINI_SEGWAY_RC_NUM_OF_ALLOWED_INVALID_DATA_PKG
#define MINI_SEGWAY_RC_ARMING_CHANNEL 7                // top right switch
#define MINI_SEGWAY_RC_MODE_CHANNEL 4                  // top left switch
#define MINI_SEGWAY_RC_TURN_RATE_CHANNEL 0             // right stick left to right
#define MINI_SEGWAY_RC_FORWARD_SPEED_CHANNEL 2         // left stick down to up
#define MINI_SEGWAY_RC_GIMBAL_ANGLE_SETPOINT_CHANNEL 9 // top right wheel
#define MINI_SEGWAY_RC_USE_UPSAMPLING_FILTERS true
#define MINI_SEGWAY_RC_UPSAMPLING_FILTER_DAMPING 1.0f
#define MINI_SEGWAY_RC_FORWARD_SPEED_UPSAMPLING_FILTER_FREQUENCY_HZ 30.0f
#define MINI_SEGWAY_RC_TURN_RATE_UPSAMPLING_FILTER_FREQUENCY_HZ 30.0f
#define MINI_SEGWAY_RC_APPLY_EXPO true
#define MINI_SEGWAY_RC_EXPO_ALPHA 2.3f

// button
#define MINI_SEGWAY_BLUE_BUTTON_GPIO     PB_DIO_3 // PC_13, blue button
#define MINI_SEGWAY_ADD_BLUE_BUTTON_GPIO PB_DIO_2 // additional blue button

// additional leds
#define MINI_SEGWAY_LED_PERIOD_US 250000
#define MINI_SEGWAY_LED1_DOUT PB_DIO_0 // blue
#define MINI_SEGWAY_LED2_DOUT PB_DIO_1 // green

// encoders
#define MINI_SEGWAY_MOTOR1_ENCA PB_DC_MOT1_ENC_A
#define MINI_SEGWAY_MOTOR1_ENCB PB_DC_MOT1_ENC_B
#define MINI_SEGWAY_MOTOR2_ENCA PB_DC_MOT2_ENC_A
#define MINI_SEGWAY_MOTOR2_ENCB PB_DC_MOT2_ENC_B
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

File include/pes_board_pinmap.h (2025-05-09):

#ifndef PES_BOARD_PINMAP_H_
#define PES_BOARD_PINMAP_H_

#define PB_DC_MOT1_DIR      PB_14
#define PB_DC_MOT1_PWM      PB_15
#define PB_DC_MOT1_ENC_A    PA_6
#define PB_DC_MOT1_ENC_B    PC_7
#define PB_DC_MOT1_FB       PA_5

#define PB_DC_MOT2_DIR      PB_10
#define PB_DC_MOT2_PWM      PA_9
#define PB_DC_MOT2_ENC_A    PB_6
#define PB_DC_MOT2_ENC_B    PB_7
#define PB_DC_MOT2_FB       PA_7

#define PB_DC_MOT3_DIR      PC_4
#define PB_DC_MOT3_PWM      PB_13
#define PB_DC_MOT3_ENC_A    PA_0
#define PB_DC_MOT3_ENC_B    PA_1
#define PB_DC_MOT3_FB       PB_1

#define PB_DC_MOT_ENABLE    PB_9
#define PB_DC_MOT_STATE     PH_1

#define PB_STEPPER1_STEP    PB_12
#define PB_STEPPER1_DIR     PB_2

#define PB_STEPPER2_STEP    PC_6
#define PB_STEPPER2_DIR     PC_5

#define PB_STEPPER_ENABLE   PC_8
#define PB_STEPPER_RESET    PB_8

#define PB_AIN_0            PC_3
#define PB_AIN_1            PC_0
#define PB_AIN_2            PC_2
#define PB_AIN_3            PC_1

#define PB_DIO_0            PA_4
#define PB_DIO_1            PB_0
#define PB_DIO_2            PA_15
#define PB_DIO_3            PC_13

#define PB_SERVO_0          PB_DIO_0
#define PB_SERVO_1          PB_DIO_1
#define PB_SERVO_2          PB_DIO_2
#define PB_SERVO_3          PB_DIO_3

#define PB_I2C_SDA          PC_9
#define PB_I2C_SCL          PA_8

#define PB_CAN_TD           PA_12
#define PB_CAN_RD           PA_11

#define PB_SDCARD_MOSI      PB_5
#define PB_SDCARD_MISO      PB_4
#define PB_SDCARD_SCLK      PB_3
#define PB_SDCARD_CS        PA_10

#define PB_UART3_TX         PC_10
#define PB_UART3_RX         PC_11

#define PB_UART5_TX         PC_12
#define PB_UART5_RX         PD_2

#define PB_USER_BUTTON      PH_0

#endif /* #ifndef PES_BOARD_PINMAP_H_ */

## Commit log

2024-03-04 Added PwmIn, so i dont loose it
    [PwmIn.cpp]
2024-03-07 Simplify PpmIn and implemented SerialStream reset fcn
    [PwmIn.cpp]
2024-03-08 Included eigen libary and updated EncoderCounter clock registers for TIM2
2024-03-22 Not really cleaned up commit, everything except encoder 2 is working
2024-03-29 Minor changes, encoders on L432KC are breaking the current code
2024-03-29 Adjustments in IMU, IMU resp. Mahony still needs tuning but could work for PES Board. Strange offset in acc z though
2024-03-30 Implemented rc upsamling filter and some crucial checks so no old rc data send from the remote will become valid when switching the rc on
2024-04-12 Changing config file to assign proper pins to Nucleo-F446RE Adding kinematics for turning Importing and developing new IMU Changes in matlab file for proper ploting data
2024-04-15 All data is available, changes to imu and stuff
2024-05-08 Refactoring, clean up and analytical model of dc motor 31:1
2024-05-08 Tuned and double checked rc upsampling filters
2024-06-01 Fixed all compiler errors and updated eigen
    [config.h]
2024-06-05 Adjustments for Pololu driver
2024-06-05 Latest changes, most of the hardware running correctly
    [Motor.cpp, config.h, main.cpp]
2024-06-06 Pololu D25 motors chirp signal measurements
2024-06-25 Minor bugfix and added chirp experiment from standing segway
    [Motor.cpp, config.h]
2024-06-27 Added LED logic
2024-06-27 Changed some logic parts and calibrated orange segway imu acc
2024-07-02 Bugfix in reset logic, set static acc bias to zero, removed unnecessary includes
    [config.h]
2024-07-03 Readme development and CAD files added
    [NDT_FRAME_MAIN_V1.stl, NDT_FRAME_MAIN_V1.stp, NDT_FRAME_WHEEL_BASE.stl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]
2024-07-31 Changes in the frame
    [NDT_FRAME_MAIN_V1.stl, NDT_FRAME_MAIN_V1.stp]
2024-08-16 Swapped x- and y imu sign according to swapped imu mounting
2024-08-19 Step files added for additional hardware
    [25d-metal-gearmotor-34-47-encoder.step, 25d-metal-gearmotor-34-47.step, Skate Wheel 84×24mm - Black.step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]
2024-08-20 Documentation updated
    [PolarityProtection.SchDoc, PowerSupply5V.SchDoc, Segway_Charging_Board.PrjPcb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]
2025-01-30 Updated eigen according to PES-Board and tried to make it also work on Mbed Studio
2025-02-24 Implemented and calibrated servo, main file currently for testing servo only
2025-02-25 Added datasheet from servo and updated hardwarelist_F446RE.txt
2025-02-25 Implemented SoftPWM for gimbal servo, working, filter needs tuning
2025-05-09 !changed IMU interface to I2C
2025-05-14 added Maxon motor technical specification
    [Motor_comparison.xlsx, Shopping_list_New_Segway.xlsx]
2025-05-21 Added rc wheel input, ready for gimbal
2025-05-23 Gimbal is ready
    [Shopping_list_New_Segway.xlsx, servo_camera_relationship.csv]
